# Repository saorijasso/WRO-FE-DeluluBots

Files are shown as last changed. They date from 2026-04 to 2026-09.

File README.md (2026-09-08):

WRO 2026 Future Engineers - DeluluBots
====

## Table Of Contents
1. [Team](#1-team)
2. [Our Robot](#2-our-robot)
3. [Hardware](#3-hardware)
    * 3.1. [Mobility Management](#31-mobility-management)
    * 3.2. [Power and Sense Management](#32-power-and-sense-management)
4. [Software](#4-software)
    * 4.1. [Computer Vision](#41-computer-vision)
    * 4.2. [Vehicle Control](#42-vehicle-control)
5. [DIY Game Field](#5-diy-game-field)  
6. [License](#6-license)

## 1. Team

<p align="center">
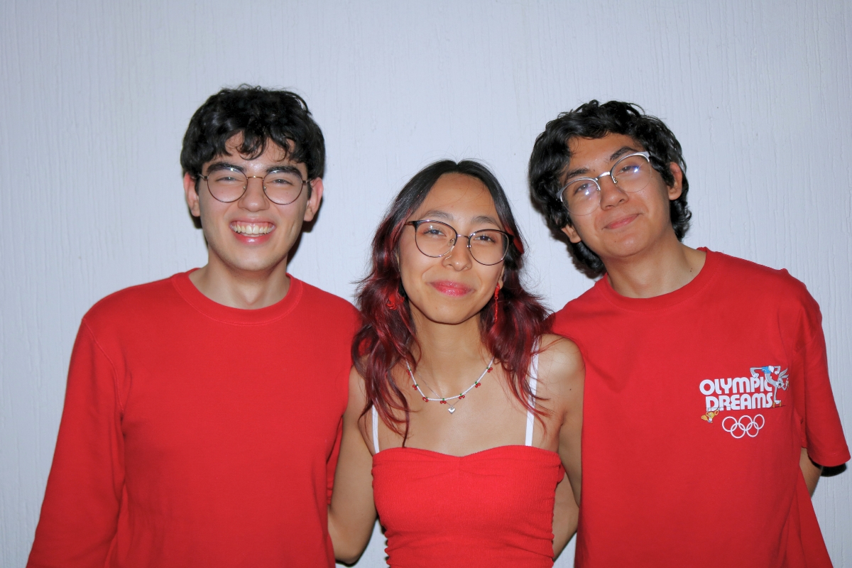
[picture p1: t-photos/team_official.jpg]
DeluluBots Official Team Photo
  
</p>

<p align="center">
  <strong>DELULUBOTS</strong><br>
  <em>Delulu Today, Limitless Tomorrow.</em>
</p>

We are **DeluluBots**, an independent robotics team of students passionate about **robotics, programming, electronics, and innovation**.

**DeluluBots was born from a simple but ambitious dream: to build our own robot and compete in WRO.** At the beginning, it seemed like a delulu idea—we had limited resources, little experience with many of the technologies involved, and no clear way to afford the journey ahead. But instead of seeing those limitations as a reason to stop, we saw them as a reason to start. That mindset became the foundation of our team.

> *Delulu* is an informal term for being “delusional” in an optimistic way: believing in something that may seem unrealistic and choosing to pursue it anyway.

Our journey is guided by one simple idea: **“Delulu Today, Limitless Tomorrow.”** As an independent team, we have worked hard to build a competitive robot while finding ways to make our participation possible. To help cover the costs of our robot and our trip to the national competition, we started **selling homemade cookies and spicy gummy candies in our city**. Every sale brought us one step closer to our goal.

More than building a robot, we aim to grow as people and engineers capable of **creating, innovating, and turning ideas into reality**. WRO has encouraged us to learn beyond what we are normally taught at university, explore technologies we had never worked with, and solve challenges independently.

Through every failure and iteration, we have learned that **perseverance is just as important as technical knowledge**. We are proud of how far we have come and excited to keep learning, improving, and staying *delulu*.

---

### Best & Fun Moments

<p align="center">
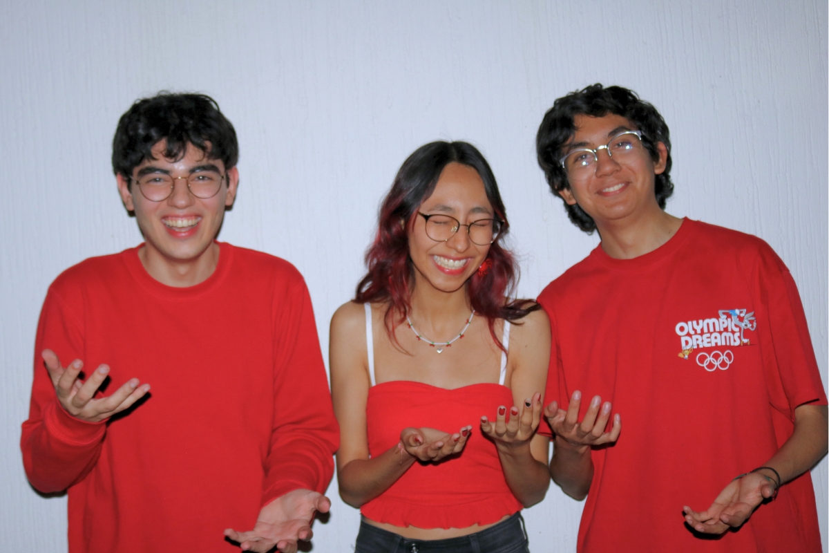
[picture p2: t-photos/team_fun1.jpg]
DeluluBots Fun Moment 1
  
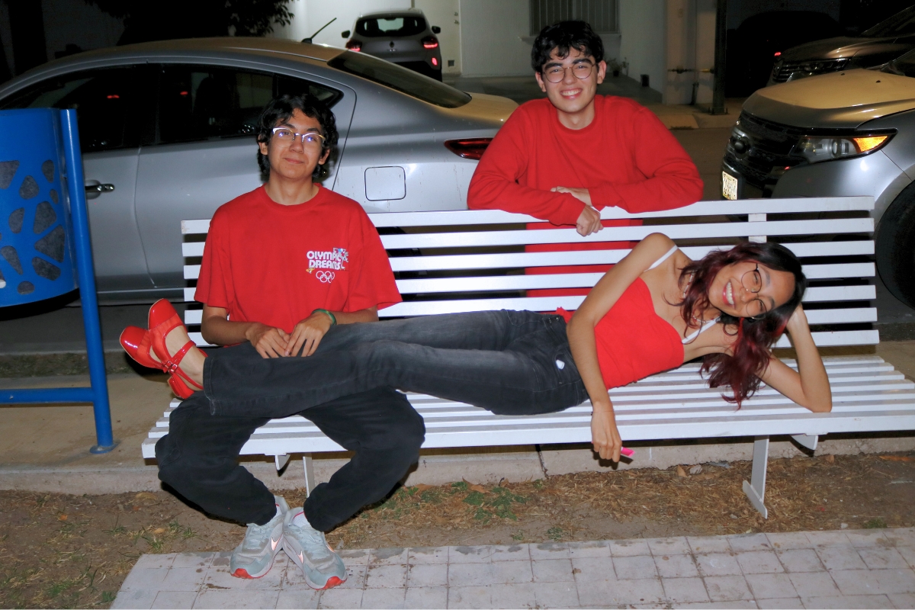
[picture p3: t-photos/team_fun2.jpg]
DeluluBots Fun Moment 2
  
</p>

<p align="center">
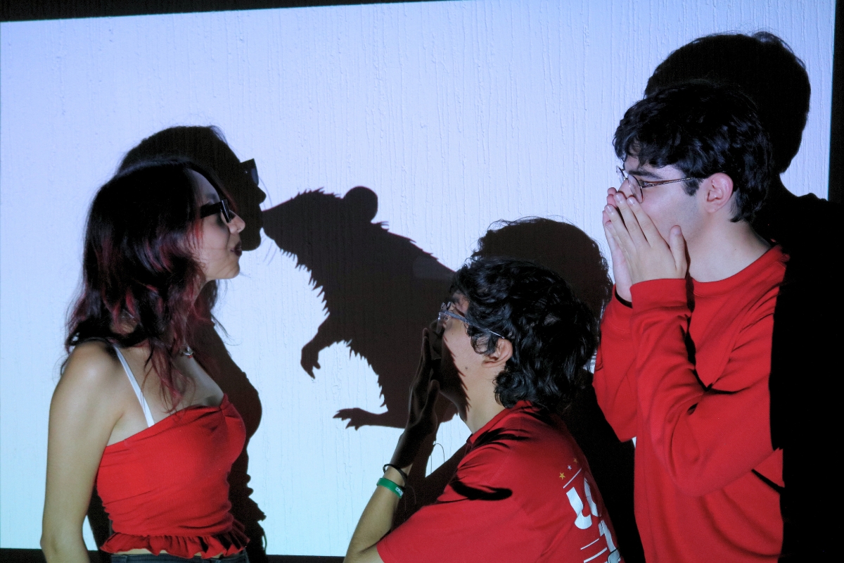
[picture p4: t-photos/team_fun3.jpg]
DeluluBots Fun Moment 3
  
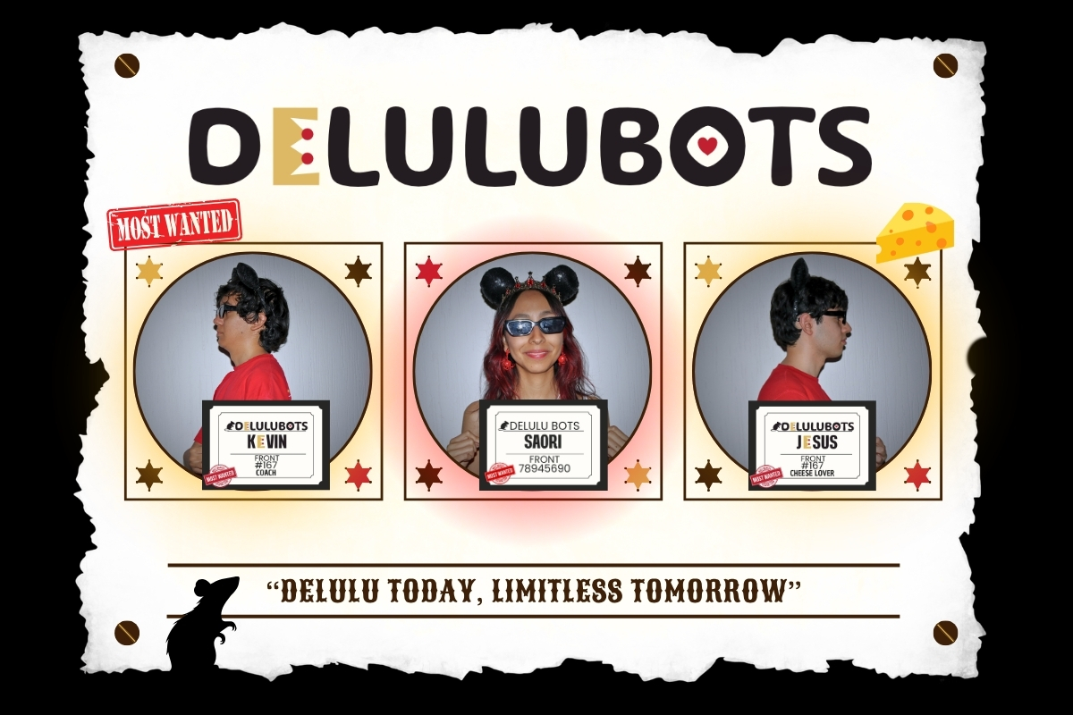
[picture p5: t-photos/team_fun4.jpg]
DeluluBots Fun Moment 4
  
</p>

---

### Team Members

<table>
<tr>
<td width="65%" valign="top">

## **Saori Jasso**

**Electronics · PCB Designer · Software Developer**

**Age:** 19

I am an **Information Technology Engineering student** and was responsible for the robot’s electrical system, from **selecting components and designing the PCB** to developing the systems that allow it to power on with just two buttons.

I also contributed to the **software development** and was responsible for **designing and building our DIY Game Field** for testing and practice.

WRO gave me the opportunity to design my **first PCB** and challenge myself with technologies I had never worked with before. Since middle school, robotics has been one of my greatest passions, and I hope to **inspire more girls to explore STEM, pursue engineering, and discover the same passion for robotics.**

</td>

<td width="35%" align="center" valign="middle">

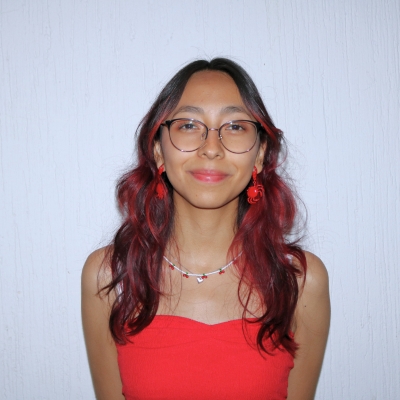
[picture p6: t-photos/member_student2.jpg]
Saori Jasso


</td>
</tr>
</table>

---

<table>
<tr>
<td width="65%" valign="top">

## **Jesús Morales**

**Mechanical & CAD Designer · Software Developer**

**Age:** 19

I am an **Information Technology Engineering student** and served as the Mechanical & CAD Designer and Software Developer for our robot.

This project marked my first time fully designing an **entire mechanical system from scratch in CAD**—a challenge that required balancing spatial constraints, weight distribution, and structural integrity.

My passion for technology started at a young age, but growing up in my hometown, hands-on STEM opportunities were limited. Moving to Mexico gave me the chance to explore robotics throughout my school years, shaping my path into engineering.

WRO has been an incredible opportunity to **push my technical limits**, and I hope to inspire others to pursue STEM regardless of their background.

</td>

<td width="35%" align="center" valign="middle">

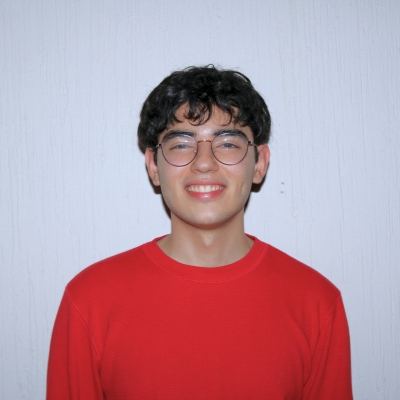
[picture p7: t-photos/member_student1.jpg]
Jesús Morales


</td>
</tr>
</table>

---

<table>
<tr>
<td width="65%" valign="top">

## **Kevin Rucoba**

**Coach**

**Age:** 21

I am a **Software Development Engineering student** and have supported and advised the team throughout all areas of the project.

From helping with **technical challenges and brainstorming ideas** to guiding decisions and overcoming unexpected problems, I've always been there to provide a different perspective when needed.

My goal is to **support their ideas, share my experience, and help them turn their ideas into reality** while encouraging them to learn, experiment, and grow as a team.

I also helped the team stay focused on our goals, encouraged us to keep improving after setbacks, and shared the experience needed to approach challenges with **confidence, creativity, and perseverance**.

</td>

<td width="35%" align="center" valign="middle">

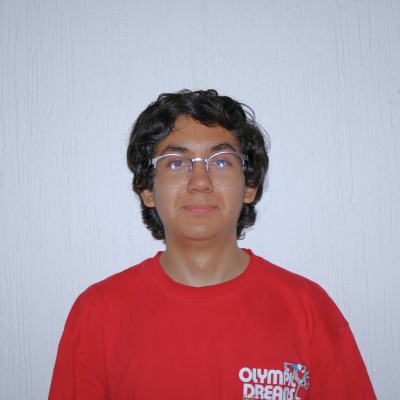
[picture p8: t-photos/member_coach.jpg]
Kevin Rucoba


</td>
</tr>
</table>

---

## 2. Our Robot

### Performance Videos

Take a look at our robot in action during the WRO 2026 Future Engineers challenges.

<table>
<tr>
<td align="center" width="50%">

<strong>Open Challenge</strong>

<a href="https://www.youtube.com/watch?v=468RyVULAOA">
  
</a>

<br>

<a href="https://www.youtube.com/watch?v=468RyVULAOA">
  Watch the Open Challenge Video
</a>

</td>

<td align="center" width="50%">

<strong>Obstacle Challenge</strong>

<a href="https://youtu.be/EnNW7pR3liw">
  
</a>

<br>

<a href="https://youtu.be/EnNW7pR3liw">
  Watch the Obstacle Challenge Video
</a>

</td>
</tr>
</table>

## 3. Hardware

### 3.1. Mobility Management

#### Chassis Overview

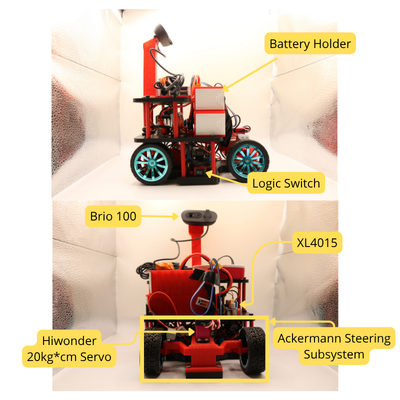
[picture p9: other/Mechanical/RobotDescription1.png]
Robot mechanical overview 1

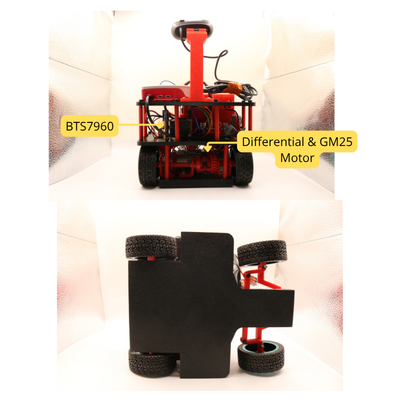
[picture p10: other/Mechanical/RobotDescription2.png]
Robot mechanical overview 2

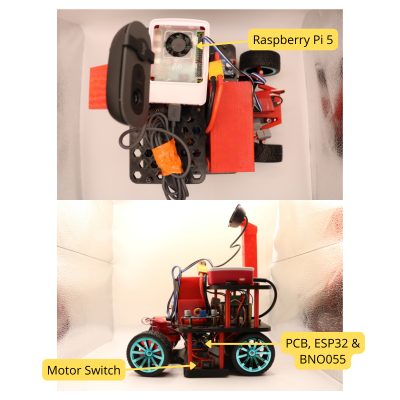
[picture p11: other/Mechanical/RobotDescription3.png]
Robot mechanical overview 3


*Overview of the robot showing the main mechanical subsystems, components and their relative positions.*

The mechanical design was developed as an integrated system, where the chassis provides the structural base for the drivetrain, steering mechanism, battery, camera, and other components. The position of each subsystem was selected according to the available space and the interaction between mechanical components.

#### Torque and Velocity Reasoning

When sizing our drivetrain, we started with basic longitudinal vehicle dynamics (Newton's 2nd law). Since the track is flat and we're moving relatively slowly, aerodynamic drag doesn't really matter. We only need to overcome inertia and rolling resistance to keep the robot moving.

**Base Parameters for our Model**

| Parameter | Value | Justification |
| :--- | :--- | :--- |
| **Robot mass (m)** | 1.45 kg | Operating just under the WRO 1.5 kg limit, maximizing our weight budget for structural reinforcement. |
| **Wheel radius (r)** | 32.5 mm | Measured from our 65 mm rubber tires. |
| **Target acceleration (a)** | 1.0 m/s² | Experimentally derived. Past 1.0 m/s², the wheels start slipping before the motor maxes out, and camera vibrations cause our vision pipeline to drop frames. |
| **Rolling resistance (Crr)** | ≈ 0.03 | Standard empirical estimate for rubber tires on synthetic surfaces. |
| **Gravity (g)** | 9.81 m/s² | Standard constant. |

> **Track Friction Unknown:** Since we couldn't afford the official competition mat, we built a DIY track using a standard tarpaulin (see our full guide in the [DIY Low-Cost Competition Track](#5-diy-game-field) section). We obviously can't measure exactly how its friction compares to the official 500 g/m² PVC mat. To compensate for this, we built a fairly large safety margin into our torque calculations.

**Force and Torque Math**

| Step | Formula | Result |
| :--- | :--- | :--- |
| **Inertial force** | Fa = m·a | 1.45 N |
| **Rolling resistance** | Frr = Crr·m·g | 0.427 N |
| **Wheel torque** | Tw = (Fa + Frr)·r | 0.061 N·m |
| **Required Motor torque** | Tm = Tw / η | **0.087 N·m** |

*Note: The 70% mechanical efficiency (η = 0.70) accounts for the friction we lose through our 3D-printed PETG differential (bevel gears and hex couplings).*

---

#### Motor and Driver Selection

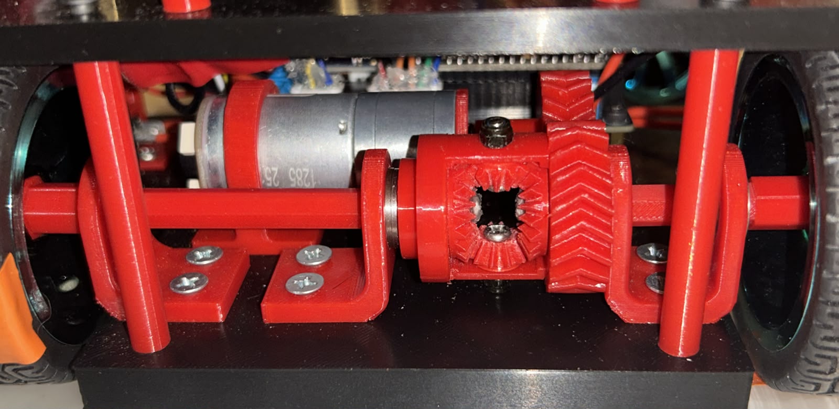
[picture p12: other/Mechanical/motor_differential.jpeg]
Image: GM25-370 motor mounted with PETG differential


**Motor: GM25-370, 12V, 330 RPM**  
The datasheet gives a continuous rated torque of 0.57 N·m (at 1.7 A) and a stall torque of 1.18 N·m (at 5.6 A). Since the robot is constantly driving and the wheels are never locked, we only use the continuous rating to size the system.

Our model requires 0.087 N·m, which is only about 15% of this motor's continuous capacity. We deliberately took the weight penalty of an oversized motor for a few practical reasons:
1. **Thermal Headroom:** Operating a motor near its limit generates a ton of heat. Staying at ~15% load keeps the motor completely cool, meaning we don't experience any RPM sag or battery voltage drops toward the end of a run.
2. **Friction Buffer:** If the official competition mat turns out to be much stickier than our tarp, this torque buffer gives us enough margin to avoid stalling in normal operation.
3. **Overcoming Mechanics:** The extra torque easily powers through the friction of our PETG differential, keeping our PID speed control crisp and responsive.

**Driver: Transitioning to the BTS7960**  
We originally prototyped with a TB6612FNG driver, but realized it was a major single point of failure. It's only rated for 1.2 A continuous per channel, and our motor can spike up to 5.6 A if it stalls (like bumping a wall or getting stuck).

Instead of risking a blown driver on the track, we swapped to a **BTS7960**. It’s rated for 43 A. It takes up more space on the chassis, but it greatly reduces the chance of the driver overheating. We chose reliability over spatial economy.

---

#### 3D Printing & Structural Optimization

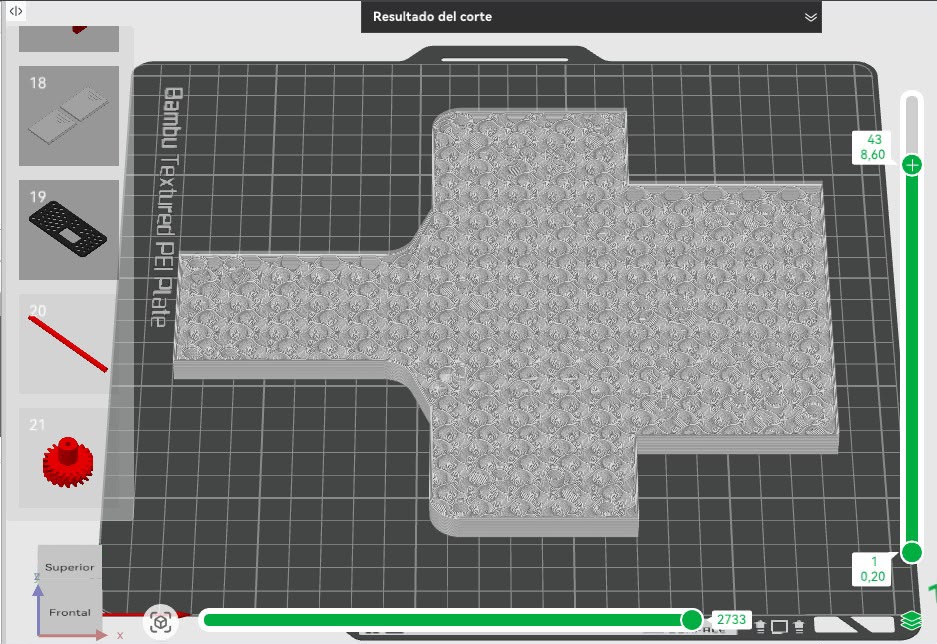
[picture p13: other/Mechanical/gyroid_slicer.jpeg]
Image: Gyroid infill pattern in slicer or printed part


To iterate quickly, we 3D printed all our custom mechanical parts using **PETG**, which gives us much better impact resistance and layer adhesion than standard PLA.

**Prototyping phase:**  
We printed early test fits using an **8% Gyroid infill**. It allowed us to print super fast and save filament during the trial-and-error phase. The Gyroid pattern distributes stress equally across the X, Y, and Z axes, so the pieces held their shape well. However, when we actively applied manual stress tests to find their limits, they eventually snapped. This proved they were strictly prototypes and nowhere near strong enough to survive the mechanical stress of a real competition.

**Final Production Parts:**  
For the final parts, we prioritized reliability so we optimized the slicer settings to get as much strength as possible without adding too much weight:
* **Wall Loops:** Increased from 2 to 3.
* **Top/Bottom Shells:** Increased from 2 to 3.
* **Gyroid Infill:** Bumped slightly to 15%.

**The result:** With these settings, we were able to add strength mainly where it matters without adding too much material. This kept our parts structurally rigid without unnecessarily increasing our total mass or messing up our calculated acceleration dynamics.

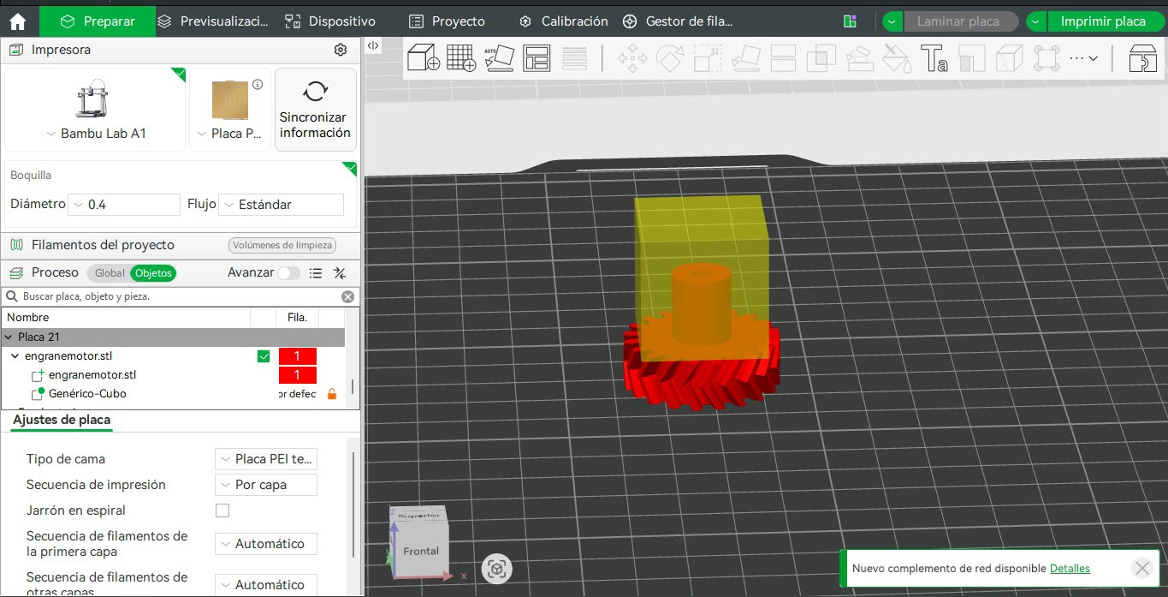
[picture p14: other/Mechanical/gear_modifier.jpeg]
Image: Slicer view showing cylindrical modifier on the D-shaft gear


**Targeted Reinforcement: Motor Gear Hub**  
During testing, we discovered a localized failure mode in our differential. The primary drive gear mounts directly to the motor's D-shaft. Due to the continuous torque and friction from sudden acceleration, the D-shaped hole inside the PETG gear was deforming and wearing out into a circle, causing the motor shaft to spin freely without turning the transmission.

Instead of printing the entire gear with 100% infill (which would add unnecessary mass and print time), we added a cylindrical modifier in Bambu Studio specifically around the mounting hub. We assigned 6 wall loops exclusively to this modifier. This generated a highly dense, rigid core to grip the D-shaft perfectly, while leaving the outer gear teeth at the standard 15% infill, solving the stripping issue completely.

#### Steering and Traction Mechanism

We selected an **Ackermann steering system** based on the turning requirements of our robot and the characteristics of the competition field. We considered conventional steering, Ackermann steering, and anti-Ackermann steering as possible solutions.

| Steering System | Turning Geometry | Tire Slip | Low-Speed Maneuverability | Mechanical Complexity | Alignment Requirements | Suitability for Our Robot |
| :--- | :--- | :--- | :--- | :--- | :--- | :--- |
| **Conventional Steering** | Both front wheels use approximately the same steering angle | Higher during tight turns because the wheels follow different turning radii | Moderate | Low | Low | Limited |
| **Ackermann Steering** | Inner wheel turns more than the outer wheel, allowing both wheels to follow their respective turning radii | Low | High | Medium | Medium–High | **Excellent** |
| **Anti-Ackermann Steering** | Inner wheel turns less than the outer wheel | Can be advantageous in specific high-speed conditions, but may increase slip at low speeds | Low–Moderate for our application | Medium | Medium–High | Limited |

We selected Ackermann because it allows the inner and outer front wheels to follow different turning radii, reducing unnecessary tire slip during turns and providing more predictable steering behavior.

This decision was also connected to our drivetrain architecture. Since the robot uses mechanically driven wheels rather than independently controlled drive wheels, we needed a steering solution that could provide precise directional control without using differential wheel speeds as the steering mechanism. Ackermann steering allowed us to separate the steering function from the traction system while maintaining a compact mechanical architecture.

#### Steering Geometry

The steering geometry was designed in CAD using the Ackermann principle. Instead of assigning the same steering angle to both front wheels, we constructed the geometry so that the steering axes of the front wheels converge toward a common **instantaneous center of rotation**.

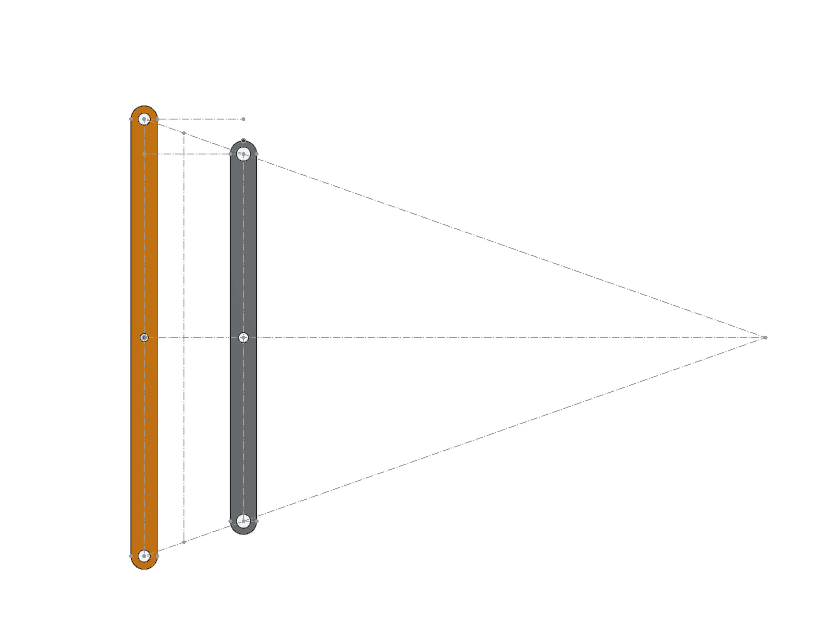
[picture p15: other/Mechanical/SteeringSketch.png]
Ackermann steering geometry


*CAD construction used to define the Ackermann steering geometry.*

This geometry determines the relative steering angles of the front wheels: the **inner wheel turns through a greater angle than the outer wheel** because it follows a smaller turning radius. This reduces unnecessary tire slip and allows the robot to maintain a more predictable trajectory during turns.

The CAD sketch was used to determine the position of the steering pivots and linkage attachment points before manufacturing the mechanism. This allowed us to translate the theoretical Ackermann geometry into a physical linkage while accounting for the available space, wheel position, and required steering range.

The steering mechanism consists of the **steering servo, servo arm, fixed steering support, linkage rods, steering arms, and front wheel assemblies**. The servo provides the input rotation, which is transferred through the linkage to both steering arms. The geometry of the steering arms produces the different steering angles required by the Ackermann configuration.

#### Space Optimization

The front section of the robot had limited space because the **front wheels, steering mechanism, and servo** had to fit within the same area. Rather than adding a separate structure to support the steering linkage, we integrated the **servo mount with the fixed steering support**.

The servo mount therefore serves two functions: it securely holds the servo and acts as the stationary reference point for the steering linkage. Small arms extending from this support provide the attachment points for the linkage rods, while the rest of the steering mechanism moves around this fixed structure.

This integration reduced the number of separate components and allowed us to make better use of the available space. It also reduced material usage while maintaining the rigidity required by the steering mechanism.

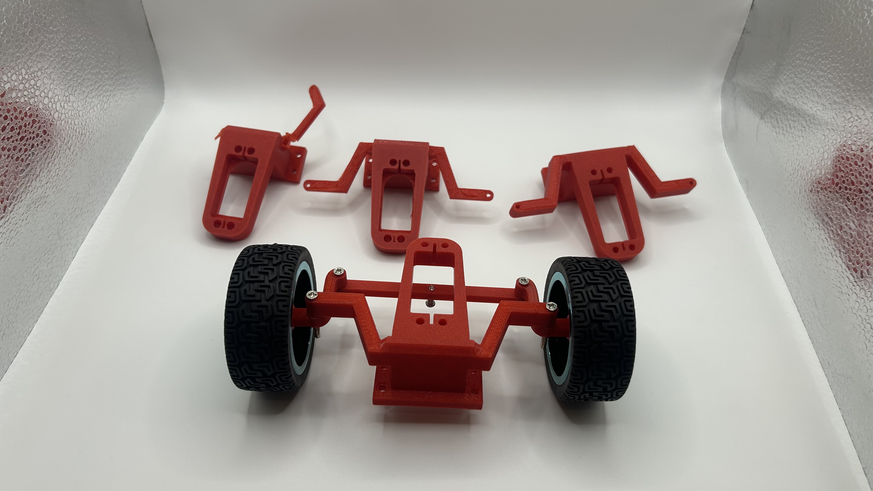
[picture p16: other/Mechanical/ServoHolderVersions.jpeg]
Servo support iterations


*Evolution of the servo support through different design iterations, showing the modifications made to improve its integration, stability, and fit within the steering mechanism.*

This was an example of adapting the theoretical steering geometry to the physical constraints of the robot rather than treating the steering system independently from the rest of the chassis.

#### Mechanical Differential

The Ackermann steering geometry also created a requirement for the traction system: the driven wheels need to be able to rotate at **different speeds during a turn**.

During a turn, the inner wheel follows a smaller radius than the outer wheel and therefore travels a shorter distance. If both driven wheels were rigidly connected to the same axle, they would be forced to rotate at the same speed. This would cause tire slip and introduce additional mechanical stress.

To solve this, we implemented a **mechanical open differential**. This allows both driven wheels to receive power from the same drivetrain while permitting them to rotate at different speeds when cornering.

We selected a mechanical differential because it provides this speed difference mechanically, without requiring independent control of the driven wheels. This complements the Ackermann steering geometry while keeping the drivetrain compact.

The differential uses **20-tooth side gears and 12-tooth spider gears**. The side gears are connected to the driven axles, while the spider gears transfer torque between them and allow relative rotation between the two sides.

The main drive gear maintains a **1:1 relationship with the motor output**, preserving the available motor speed without introducing an additional reduction stage at the differential.

#### Differential Iterations

Our drivetrain went through several iterations before reaching the final configuration. The first prototype used **spur gears** both in the motor-to-differential transmission and within the differential.

| Initial Prototype | Final Design |
| :---: | :---: |
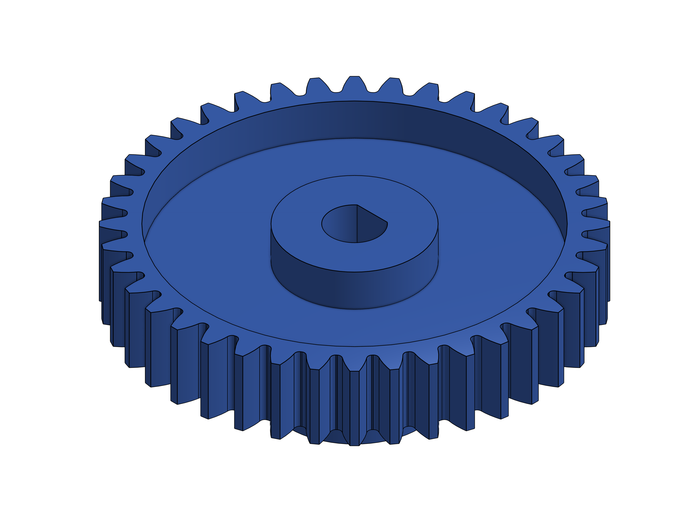
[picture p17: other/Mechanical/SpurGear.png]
Initial motor gear
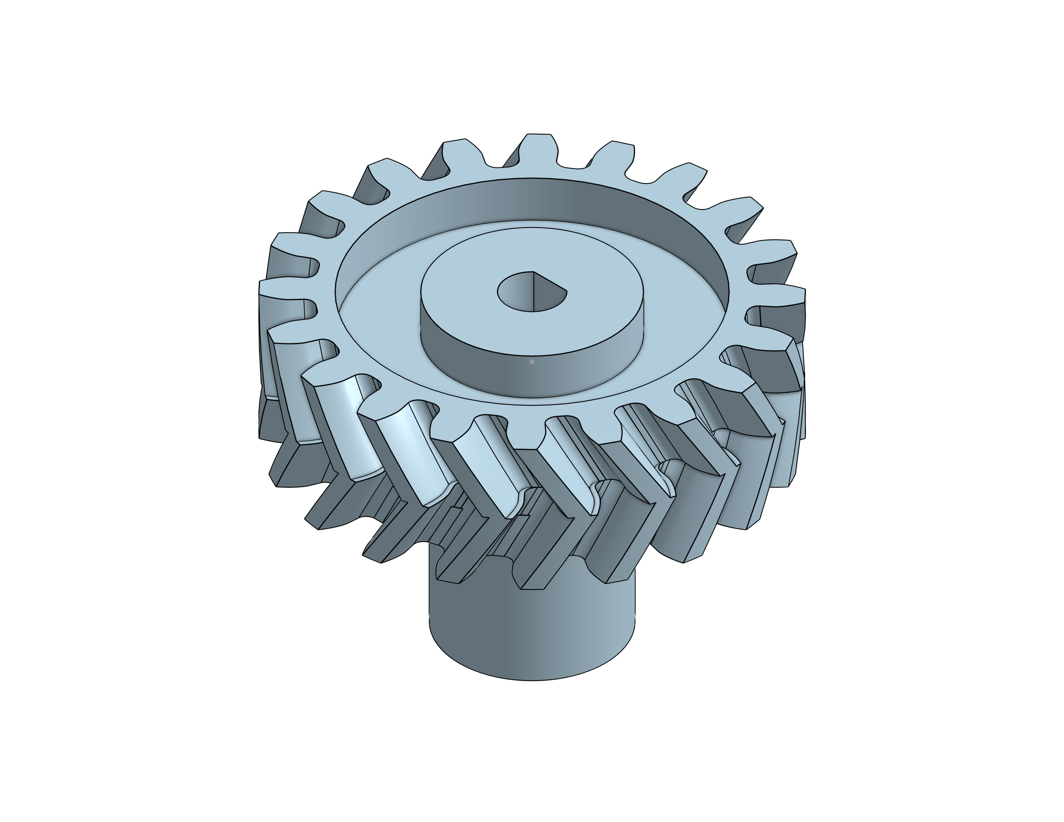
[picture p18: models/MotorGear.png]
Final motor gear
|  |  |
| *Spur gear* | *Final reinforced gear* |
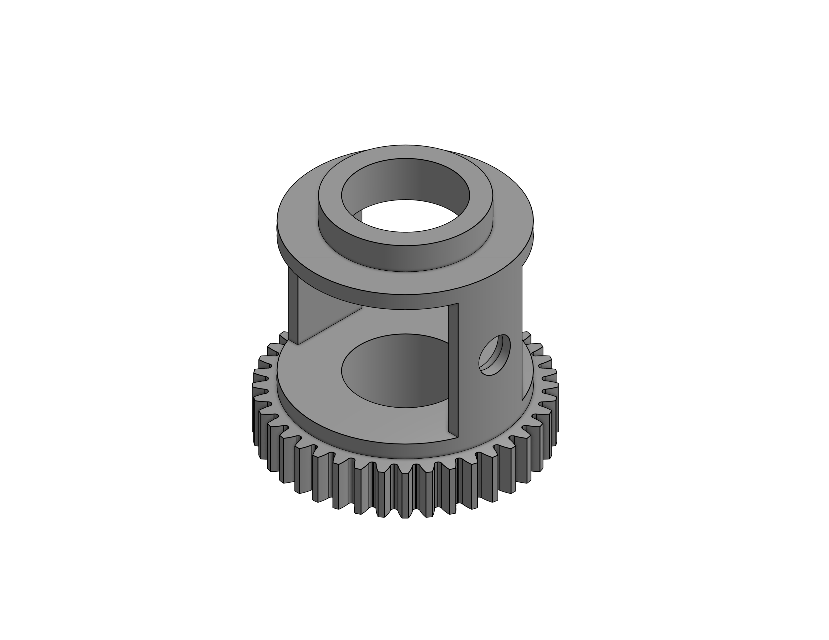
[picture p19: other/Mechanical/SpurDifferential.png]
Initial differential
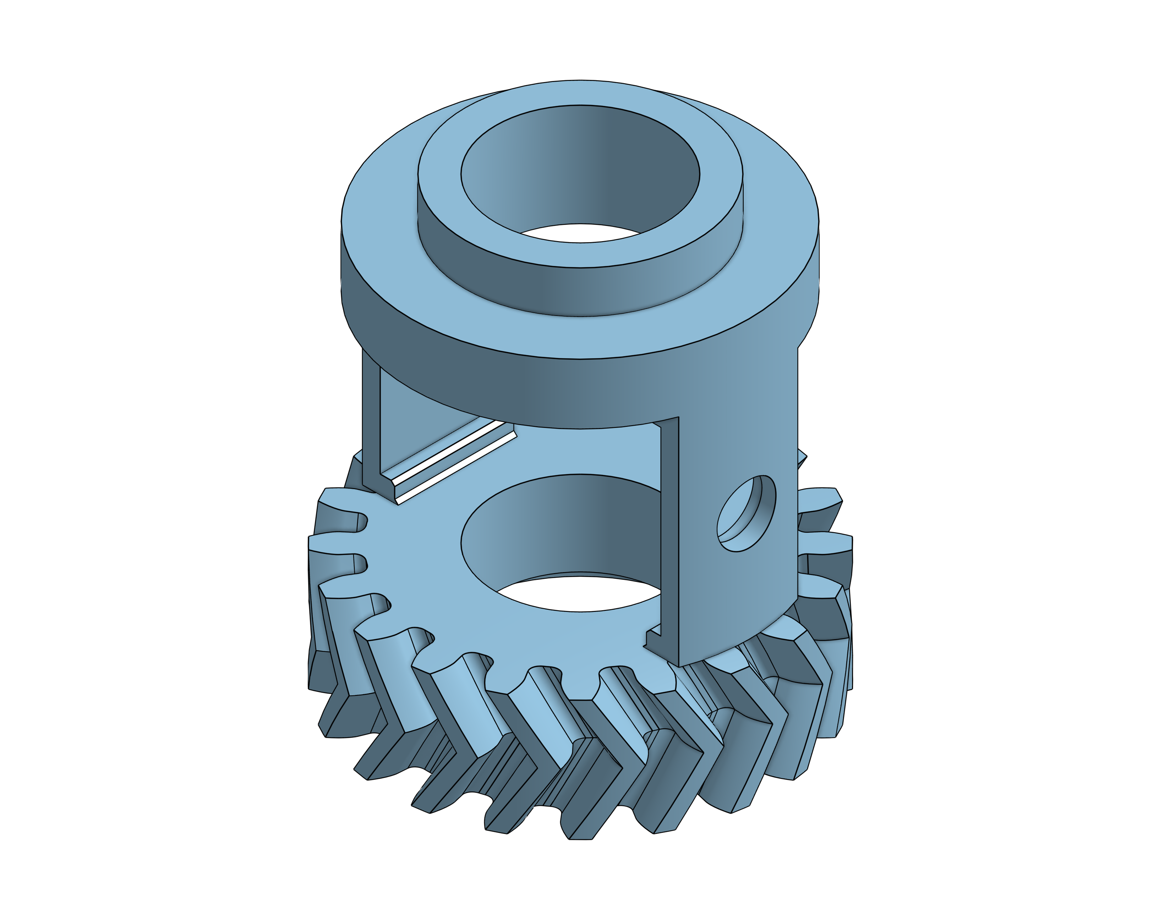
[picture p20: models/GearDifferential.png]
Final differential
|  |  |
| *Initial differential* | *Final differential* |

*Evolution of the drivetrain from the initial spur-gear prototype to the final design.*

The initial version allowed us to validate the basic drivetrain concept and confirm the interaction between the motor and differential. However, testing revealed several mechanical weaknesses that led to subsequent iterations.

The main gears were initially designed as **spur gears**. We later changed them to **herringbone gears** to improve resistance to lateral movement and maintain better alignment during operation.

#### Axle Support Iteration

During testing of the initial differential housing, we observed that the driven axles were supported at only two points. This allowed the shafts to deflect under their own load and during operation, causing them to become slightly misaligned with the differential gears.

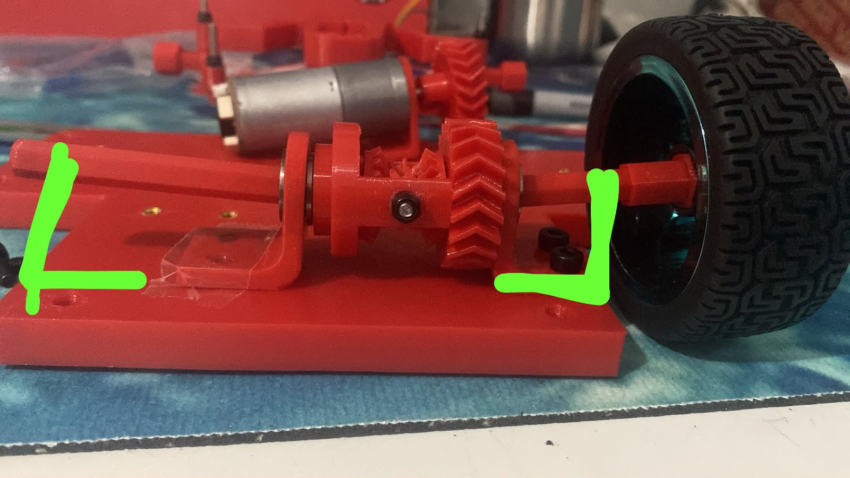
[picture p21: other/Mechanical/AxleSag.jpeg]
Initial axle support


*Initial axle configuration showing shaft deflection caused by insufficient support.*

To address this issue, we redesigned the rear support structure to provide an additional support point for the driven axles.

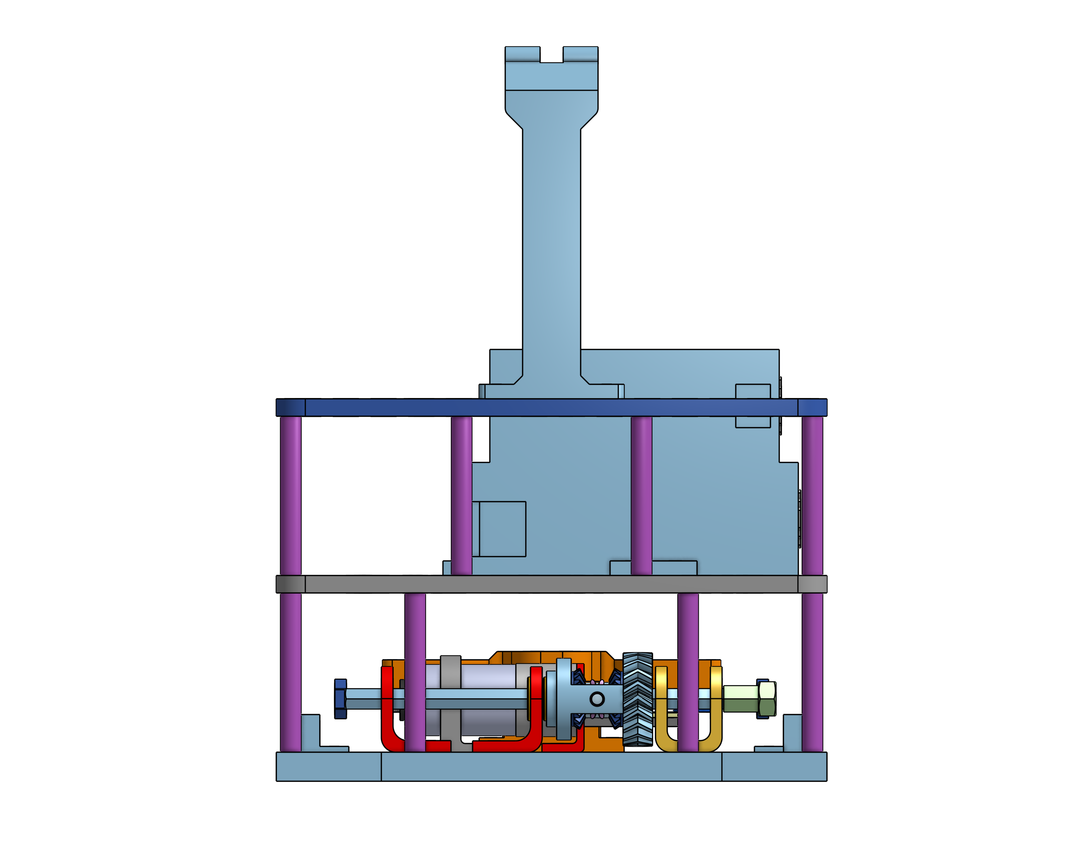
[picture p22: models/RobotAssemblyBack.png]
Axle support redesign


*Axle support redesign adding an additional constraint point to reduce shaft deflection.*

The additional support constrains the shafts along a greater portion of their length, reducing unwanted movement and helping maintain consistent alignment between the axles and the differential gears.

This modification was made specifically in response to the deformation observed during testing. Rather than increasing the overall size of the differential housing, we added support only where the deformation occurred. This improved structural stability while keeping the mechanism compact.

Additionally, the supports holding the spider gears were initially too thin and fragile. We increased their thickness and added reinforcing tabs connecting them to the main differential body. Because changing the spacing between these supports would affect the existing gear geometry, the reinforcement was added without changing their position.

Finally, during testing of the first herringbone version, the main gears could still separate slightly under load, causing the teeth to skip. We modified the differential housing to keep the gears closer together and maintain consistent tooth engagement.

These iterations allowed us to improve the drivetrain based on problems observed during physical testing, resulting in a final differential with improved **gear alignment, shaft support, structural rigidity, and power transmission reliability**.

#### Motor Support

The motor support was developed to securely hold the drive motor while maintaining its position relative to the drivetrain. In the initial version, the motor was not fully enclosed by the support structure.

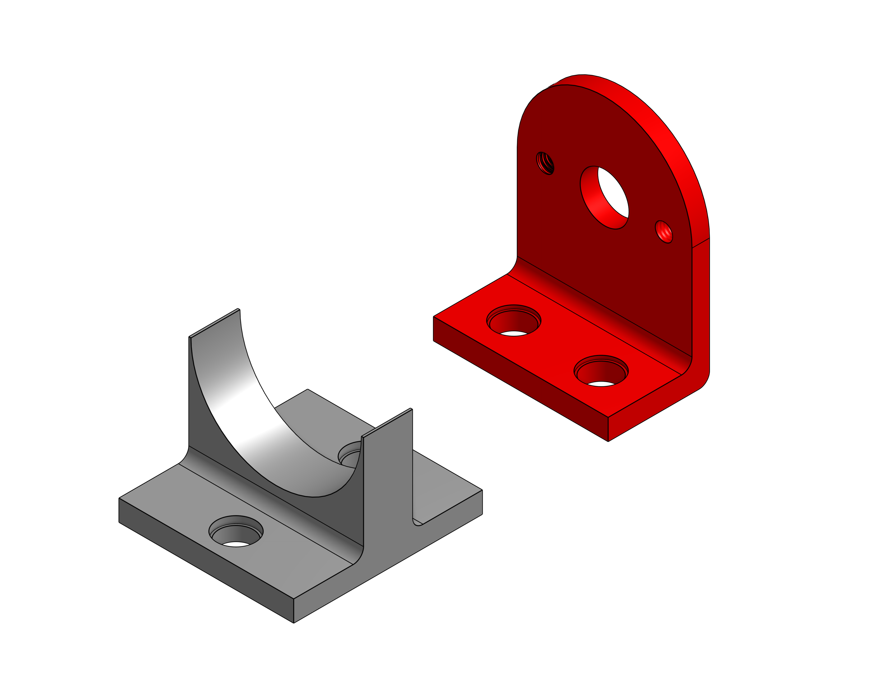
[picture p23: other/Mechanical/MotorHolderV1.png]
Initial motor support


*Initial motor support design with limited constraint around the motor.*

During testing, we observed that the torque generated by the motor caused the support to tend to move upward. This movement could affect the position of the motor and consequently the alignment between the motor output gear and the drivetrain.

To address this issue, we redesigned the support to provide greater constraint around the motor body.

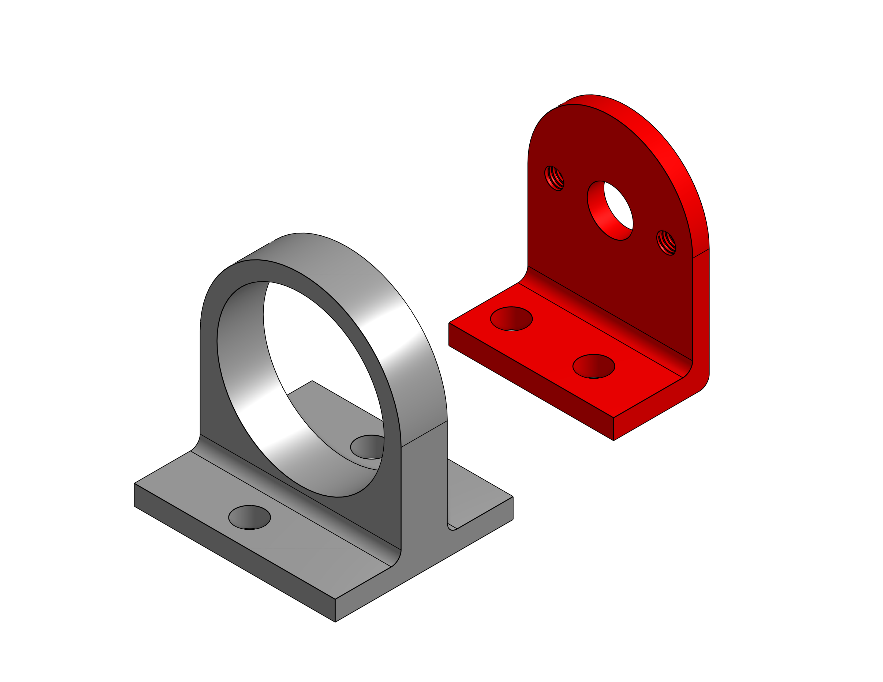
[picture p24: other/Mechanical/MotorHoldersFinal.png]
Final motor support


*Final motor support design providing greater constraint around the motor.*

The modification increased the stability of the motor mounting structure and helped maintain consistent alignment with the drivetrain during operation. Rather than increasing the size of the surrounding chassis, the support was reinforced specifically in the areas where movement was observed.

### 3.2. Power and Sense Management
This section details the hardware architecture of our vehicle, covering **component selection and strategic placement**, **power distribution**, **wiring schematics (including custom PCB design)**, **sensor calibration protocols**, and **systematic power testing strategies**.

Our design methodology goes beyond connecting components to achieve basic functionality. We engineered an electrical ecosystem focused on **reproducibility**, **safety**, **noise isolation**, and **rapid pre-competition validation**—ensuring every hardware decision directly supports our vehicle’s autonomous performance goals.

> [!NOTE]
> **Key Engineering Focus:** Prioritizing power stability through dual-battery domain isolation, noise decoupling, and custom PCB power distribution to withstand dynamic competition conditions.

### Section Overview

This module is organized into six core architecture deliverables:

<table>
  <thead>
    <tr>
      <th width="30%">Module</th>
      <th width="70%">Key Deliverables & Specifications</th>
    </tr>
  </thead>
  <tbody>
    <tr>
      <td><b>01. Control Architecture</b></td>
      <td>Dual-controller processing hierarchy (Raspberry Pi 5 + ESP32) and UART communication flow.</td>
    </tr>
    <tr>
      <td><b>02. Power System Architecture</b></td>
      <td>Dual-domain battery isolation (2500 mAh logic & 2300 mAh actuators), voltage regulation rails, and safety protocols.</td>
    </tr>
    <tr>
      <td><b>03. Power Budget & Runtime</b></td>
      <td>Worst-case current consumption matrix, mathematical power models, and battery life estimations.</td>
    </tr>
    <tr>
      <td><b>04. Component Specifications</b></td>
      <td>Comprehensive procurement matrix, hardware parameters, engineering rationale, and placement strategy.</td>
    </tr>
    <tr>
      <td><b>05. Iterative Hardware Prototyping</b></td>
      <td>Pre-PCB circuit mapping, hand-drawn schematics, and preliminary electrical testing.</td>
    </tr>
    <tr>
      <td><b>06. Custom PCB Integration</b></td>
      <td>Carrier board design, dual-switch power activation, decoupling strategies, and trace routing.</td>
    </tr>
  </tbody>
</table>

---

### Control Architecture

The vehicle's electronics rely on a distributed processing hierarchy, separating high-level perception and computer vision from real-time low-level actuation:

```text
┌────────────────────────────────┐                 ┌────────────────────────────────┐
│        Raspberry Pi 5          │   UART Serial   │              ESP32             │
│  (High-Level Vision & Logic)   │ ──────────────> │  (Low-Level Real-Time Control) │
└───────────────┬────────────────┘                 └───────────────┬────────────────┘
                │                                                  │
         USB    │                                   PWM / I2C / IO │
                ▼                                                  ▼
   ┌──────────────────────────┐                      ┌──────────────────────────┐
   │    Logitech Brio 100     │                      │ Actuators & Sensors      │
   │    (1080p Camera)        │                      │ (Motor, Servo, IMU)      │
   └──────────────────────────┘                      └──────────────────────────┘
```

* **Raspberry Pi 5 (Vision & Logic):** Processes the camera feed using OpenCV to detect the track boundaries. It acts as the main decision-maker, calculating the necessary steering angle, motor power, and evaluating state conditions (e.g., boolean flags for lap counting or current run state). It sends these specific variables to the ESP32 via UART serial communication.
* **ESP32 (Hardware Control):** Receives the angle, power, and state commands from the Raspberry Pi. It acts as the physical bridge: reading data from the BNO055 IMU and motor encoder, and translating the Pi's commands into actual PWM signals to drive the BTS7960 motor driver and steering servo.

---

### Electrical System Architecture

<p align="center">
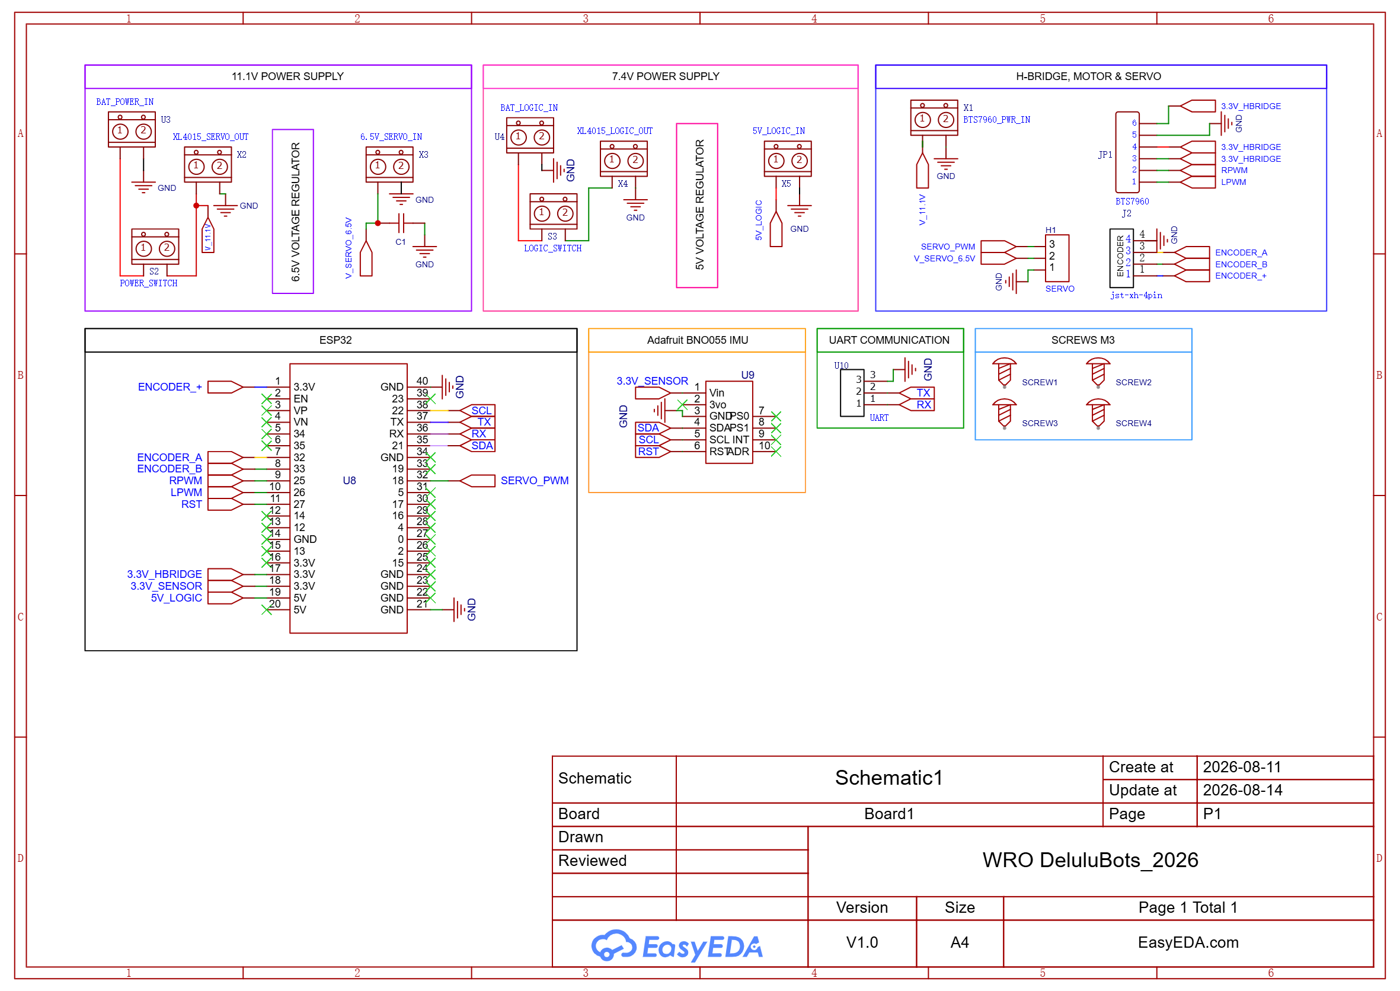
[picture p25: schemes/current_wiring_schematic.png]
Current Wiring Schematic
  
  <br>
  <em>Official electrical schematic detailing power distribution and signal routing.</em>
</p>

#### Dual-Battery Domain Isolation

To eliminate voltage dips (brownouts) and inductive noise caused by high-current motor actuation, the electrical system is divided into two fully isolated power domains:

* **Logic & Perception Domain (7.4V LiPo, 2500 mAh 2S):** Powers low-voltage digital hardware, sensors, processing boards, and the USB camera.
* **Actuator Domain (11.1V LiPo, 2300 mAh 3S):** Supplies raw current to mechanical loads, isolating inductive back-EMF and switching noise from sensitive processing logic.

```text
┌────────────────────────────────────────────────────────────────────────┐
│                        ACTUATOR POWER DOMAIN                           │
└────────────────────────────────────────────────────────────────────────┘
                       ┌──────────────────────┐
                       │   11.1 V LiPo        │
                       │   2300 mAh (3S)      │
                       └──────────┬───────────┘
                                  │
                   ┌──────────────┴──────────────┐
                   │                             │
              Direct 11.1 V                 ┌────▼────┐
                   │                        │ XL4015  │
                   ▼                        │  6.5 V  │
             ┌───────────┐                  └────┬────┘
             │  BTS7960  │                       │
             └─────┬─────┘                  ┌────┴─────┐
                   │                        │ Hiwonder │
                   ▼                        │ 20kg·cm  │
              ┌─────────┐                   │  Servo   │
              │ GM25    │                   └───────────┘
              │ Motor   │
              └─────────┘

┌────────────────────────────────────────────────────────────────────────┐
│                          LOGIC POWER DOMAIN                            │
└────────────────────────────────────────────────────────────────────────┘
                       ┌──────────────────────┐
                       │   7.4 V LiPo         │
                       │   2500 mAh (2S)      │
                       └──────────┬───────────┘
                                  │
                             ┌────▼────┐
                             │ XL4015  │
                             │  5.0 V  │
                             └────┬────┘
                                  │
                    ┌─────────────┴─────────────┐
                    │                           │
              ┌─────▼─────┐               ┌─────▼─────┐
              │   ESP32   │               │ Raspberry │
              └─────┬─────┘               │   Pi 5    │
                    │                     └─────┬─────┘
       ┌────────────┼────────────┐              │
       │            │            │          USB │
   ┌───▼────┐  ┌────▼───┐  ┌─────▼─────┐        ▼
   │Encoder │  │ BNO055 │  │   UART    │  ┌───────────────┐
   │        │  │  IMU   │  │ Interface │  │ Logitech Brio │
   └────────┘  └────────┘  └───────────┘  │  100 Webcam   │
                                          └───────────────┘
```

> [!IMPORTANT]
> **Noise Suppression:** A 220 nF ceramic capacitor is placed in parallel across the servo power rail (+V/GND) to suppress high-frequency inductive voltage spikes generated by sudden mechanical steering shifts.

#### Voltage Regulation & Pre-Power Safeguards

Two XL4015 DC-DC Buck Converters step down variable battery voltages into regulated power rails:

| **Input Source** | **Regulated Output** | **Target Payloads** | **Primary Purpose** |
| --- | --- | --- | --- |
| **7.4V LiPo (2S, 2500 mAh)** | **5.0V DC** | ESP32, Raspberry Pi 5, Sensors, Camera | Clean digital rail preventing MCU/SBC brownouts. |
| **11.1V LiPo (3S, 2300 mAh)** | **6.5V DC** | Hiwonder 20 kg·cm Steering Servo | Dedicated high-torque servo rail isolated from logic. |

> [!WARNING]
> **Safety Protocol:** Buck converter output voltages are manually verified using a digital multimeter prior to connecting any microcontrollers, ensuring no over-voltage reaches 5V sensitive logic lines.
>
> | **Testing Logic Rail (5.0V)** | **Testing Actuator Rail (6.5V)** |
> | :---: | :---: |
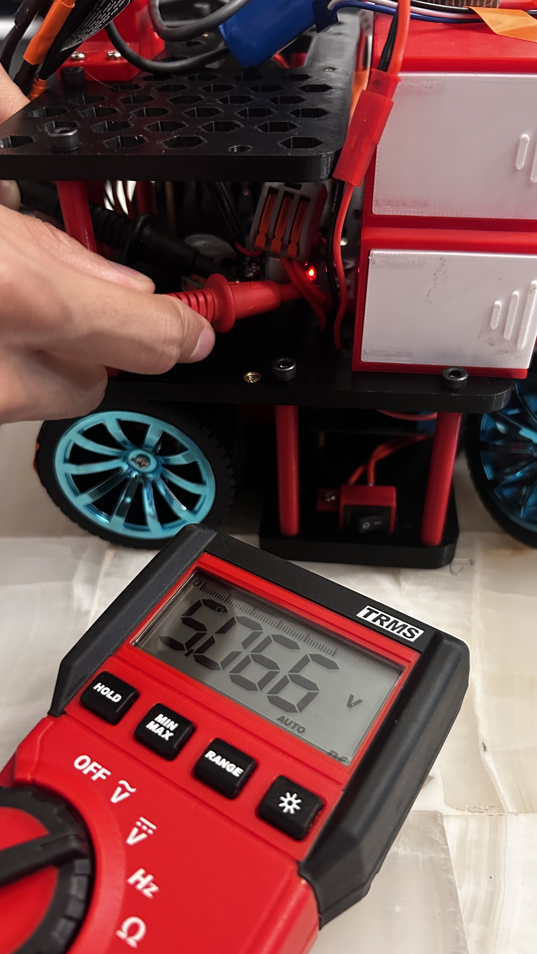
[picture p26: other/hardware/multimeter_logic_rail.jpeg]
Multimeter checking 5V buck converter
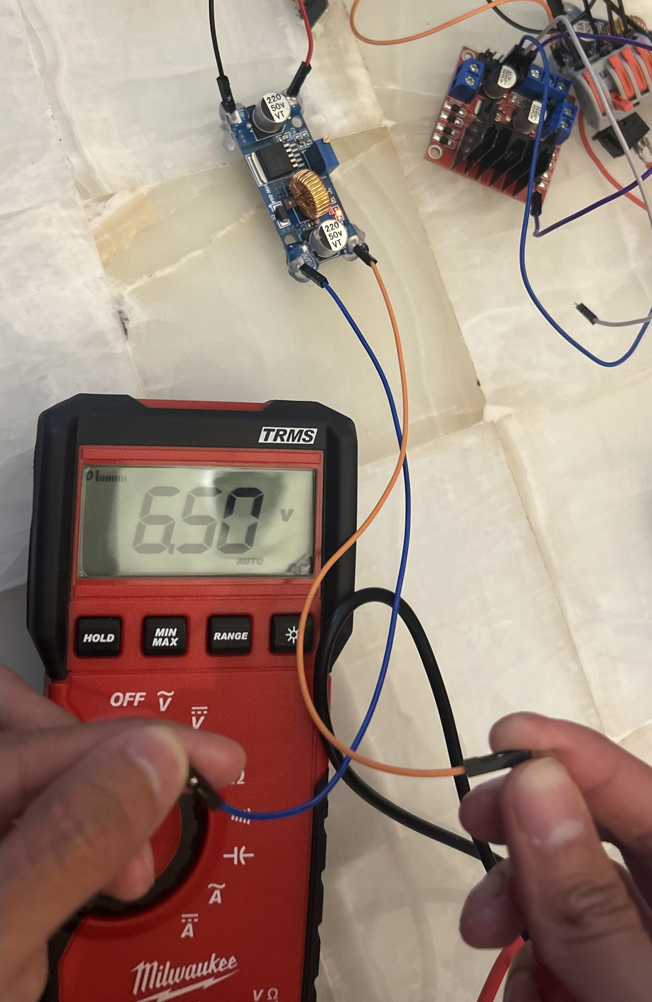
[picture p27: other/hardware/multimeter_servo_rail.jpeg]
Multimeter checking 6.5V buck converter
> |  |  |
---

### Reliability and Safety Considerations

#### Reverse Polarity Prevention

One of the most critical foreseeable assembly failures during rapid pit-stop battery swaps is reverse polarity connection. To eliminate this risk, the power distribution system does not rely solely on color-coded wire conventions (red/black):

* **Actuator Domain (11.1 V LiPo):** Terminates in a high-current **keyed XT60 connector**.
* **Logic Domain (7.4 V LiPo):** Terminates in a dedicated **keyed JST-RC connector**.

Because both connector families are mechanically polarized and asymmetrical, they physically prevent inverted insertion. This implements a reliable mistake-proofing (poka-yoke) physical safeguard, eliminating human error during high-stress competition maintenance.

---

### Current Requirements & Power Budget

#### Component Current Demand Matrix

| **Component** | **Operating Voltage** | **Current Demand / Profile** | **Supply Source** |
| --- | --- | --- | --- |
| **GM25-370 Motor** | 11.1 V | ≤ 1.7 A (Nominal) \| ≤ 5.6 A (Stall) | Direct 11.1V LiPo (3S, 2300 mAh) |
| **BTS7960 Driver** | 11.1 V | Rated up to 43 A max peak | Direct 11.1V LiPo (3S, 2300 mAh) |
| **Hiwonder Servo** | 6.5 V | Variable dynamic load (≈ 0.8 A – 2.0 A) | 11.1V LiPo → XL4015 Buck (#2) |
| **Raspberry Pi 5** | 5.0 V | High-performance digital load (≈ 1.5 A – 3.0 A) | 7.4V LiPo → XL4015 Buck (#1) |
| **ESP32 MCU** | 5.0 V | Nominal logic load (≈ 160 mA – 240 mA) | 7.4V LiPo → XL4015 Buck (#1) |
| **BNO055 IMU** | 3.3 V Logic | Low power sensor load (< 15 mA) | ESP32 Onboard 3.3V Regulator |
| **Logitech Brio 100** | 5.0 V (USB) | Powered directly via USB bus | Raspberry Pi 5 USB Port |

#### Mathematical Power Calculations

Electrical power consumption is defined by:

**P = V × I**

**1. Nominal Motor Power Consumption:**
P(motor_nom) = 11.1 V × 1.7 A = 18.87 W

**2. Worst-Case Stall Electrical Condition:**
P(motor_stall) = 11.1 V × 5.6 A = 62.16 W

*The stall power (62.16 W) represents an instantaneous transient condition used to dimension PCB trace widths and thermal clearance margins.*

#### Battery Runtime Estimation

Theoretical operational runtime (t) is estimated using nominal battery capacities:

**t ≈ Capacity (Ah) / Average Current (A)**

* **Actuator Rail (11.1V LiPo, 2300 mAh):**
  Actuator Runtime ≈ 2.3 Ah / 1.7 A ≈ 1.35 hours (≈ 81 minutes)

* **Logic Rail (7.4V LiPo, 2500 mAh):**
  Logic Runtime ≈ 2.5 Ah / 2.0 A ≈ 1.25 hours (≈ 75 minutes)

> **Real-World Operating Margin:** Accounting for ≈ 90% DC-DC buck efficiency, CPU vision spikes, and keeping battery discharge above 20% capacity (3.3V/cell cutoff), total continuous competition runtime is estimated at **45–55 minutes**, far exceeding the required competition run length.

---

### Component Selection & Specifications

The following table details the key electronic and electromechanical components selected for our vehicle, including their core technical parameters, functional role, power/interface requirements, and engineering rationale.

<table>
  <thead>
    <tr>
      <th width="11%">Component</th>
      <th width="8%">Image</th>
      <th width="20%">Key Specifications</th>
      <th width="16%">Function</th>
      <th width="20%">Power / Interface</th>
      <th width="25%">Selection Rationale</th>
    </tr>
  </thead>
  <tbody>
    <tr>
      <td><b>GM25-370 Geared Motor</b><br><i>(with encoder)</i></td>
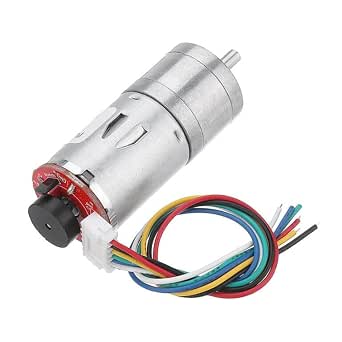
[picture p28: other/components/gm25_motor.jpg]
GM25 Motor
      <td align="center"></td>
      <td>
        • 12V Nominal<br>
        • 330 RPM<br>
        • Metal Gearbox<br>
        • Integrated Encoder
      </td>
      <td>Drive Propulsion</td>
      <td>11.1V Battery via BTS7960 Driver</td>
      <td>Provides high torque and high encoder resolution for precise closed-loop speed control.</td>
    </tr>
    <tr>
      <td><b>BTS7960 Motor Driver</b></td>
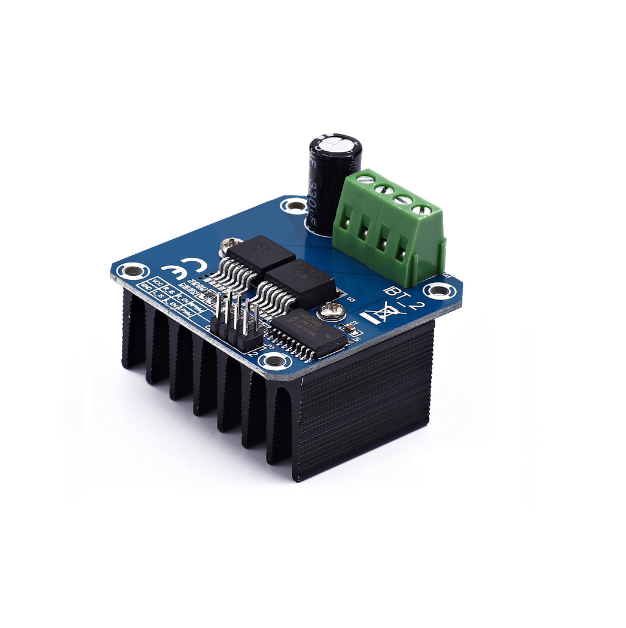
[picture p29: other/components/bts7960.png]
BTS7960 Driver
      <td align="center"></td>
      <td>
        • Max Current: 43A<br>
        • Operating Voltage: 6V–27V<br>
        • Thermal Protection
      </td>
      <td>High-Current Motor Control</td>
      <td>11.1V Power Rail + ESP32 Logic PWM/DIR</td>
      <td>Offers high current headroom, preventing thermal shutdown during heavy load or acceleration.</td>
    </tr>
    <tr>
      <td><b>Hiwonder Digital Servo</b></td>
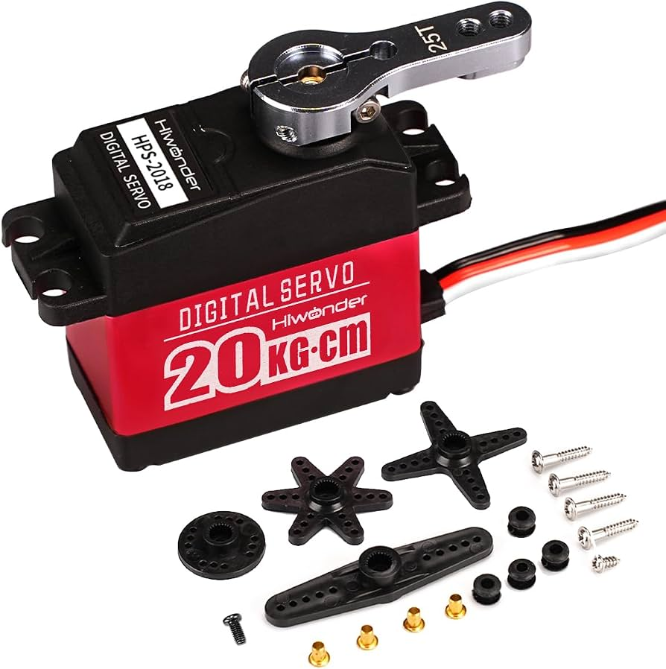
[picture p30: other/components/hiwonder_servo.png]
Hiwonder Servo
      <td align="center"></td>
      <td>
        • Torque: 20 kg·cm<br>
        • Metal Gears<br>
        • Fast Response
      </td>
      <td>Steering Actuation</td>
      <td>6.5V Regulated Power Rail (PWM Control)</td>
      <td>Metal gears and high torque ensure rigid steering alignment without mechanical backlash.</td>
    </tr>
    <tr>
      <td><b>ESP32 Dev Board</b></td>
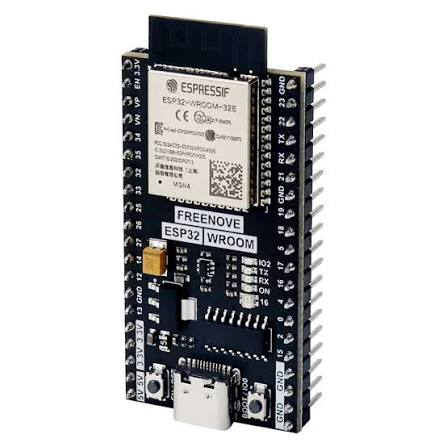
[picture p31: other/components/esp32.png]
ESP32 Board
      <td align="center"></td>
      <td>
        • Dual-Core 240MHz<br>
        • Wi-Fi / Bluetooth<br>
        • Hardware PWM
      </td>
      <td>Low-Level Microcontroller</td>
      <td>5V Regulated Logic Input (UART / I2C)</td>
      <td>High processing speed for real-time encoder readings and PID motor loops.</td>
    </tr>
    <tr>
      <td><b>BNO055 9-DOF IMU</b></td>
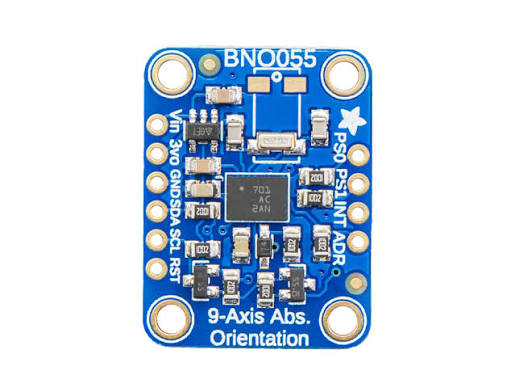
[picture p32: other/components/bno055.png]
BNO055 IMU
      <td align="center"></td>
      <td>
        • Onboard Sensor Fusion<br>
        • Absolute Orientation<br>
        • Low Drift
      </td>
      <td>Orientation Feedback</td>
      <td>ESP32 via I2C Bus</td>
      <td>Built-in sensor fusion algorithm offloads IMU filtering from the main MCU.</td>
    </tr>
    <tr>
      <td><b>Raspberry Pi 5</b></td>
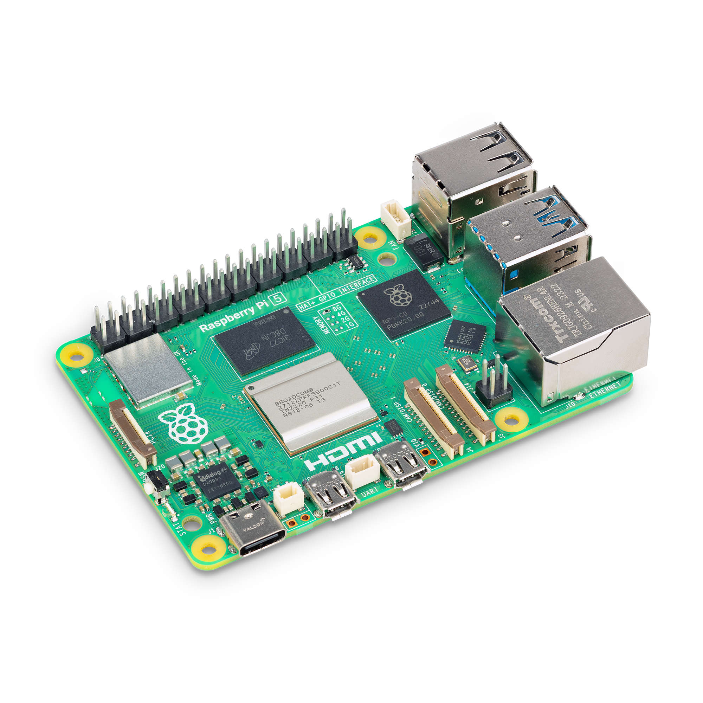
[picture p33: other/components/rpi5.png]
Raspberry Pi 5
      <td align="center"></td>
      <td>
        • Quad-Core ARM<br>
        • 16GB RAM<br>
        • USB 3.0
      </td>
      <td>High-Level Vision Processing</td>
      <td>5V Regulated Logic Rail (USB/UART Interface)</td>
      <td>Delivers high computational power and memory for real-time OpenCV image processing.</td>
    </tr>
    <tr>
      <td><b>Logitech Brio 100</b></td>
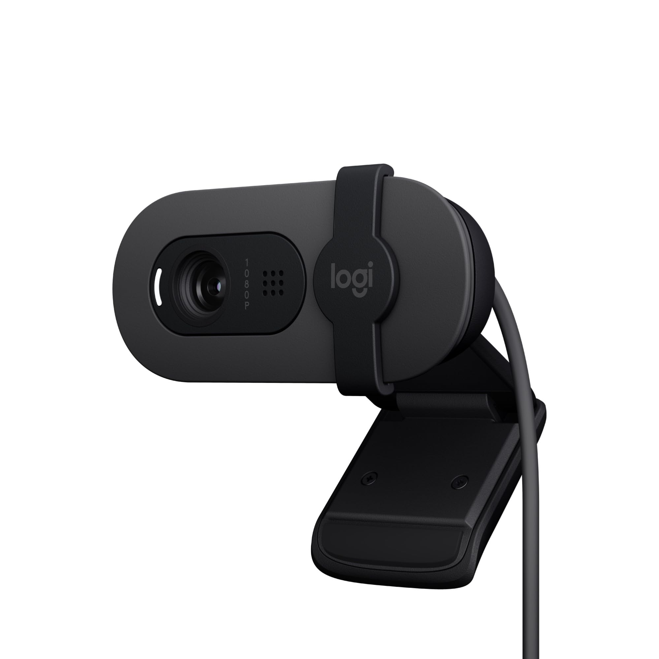
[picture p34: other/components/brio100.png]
Logitech Brio 100
      <td align="center"></td>
      <td>
        • 1080p Resolution<br>
        • Wide FOV<br>
        • Auto Light Balance
      </td>
      <td>Computer Vision Camera</td>
      <td>USB Connection to Raspberry Pi 5</td>
      <td>Provides high clarity and stable frame rates across varying ambient light conditions.</td>
    </tr>
    <tr>
      <td><b>XL4015 Buck Converters</b></td>
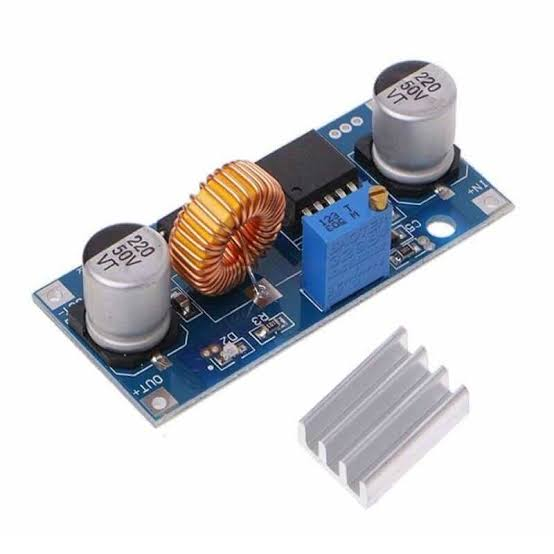
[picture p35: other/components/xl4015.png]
XL4015 Buck Converter
      <td align="center"></td>
      <td>
        • Max Output: 5A / 50W<br>
        • Adjustable Step-Down<br>
        • High Efficiency (>90%)
      </td>
      <td>Power Step-Down (Logic & Servo)</td>
      <td>Battery → Regulated Rails</td>
      <td>Drives logic circuits and servos efficiently with low heat dissipation.</td>
    </tr>
  </tbody>
</table>

---

### Strategic Component Placement (Physical Layout)

Component placement bridges our electrical schematic with the mechanical reality of the chassis. Positioning was dictated by three core constraints: **signal integrity (minimizing wire length)**, **electromagnetic interference (EMI) reduction**, and **accessibility for quick pit-stop maintenance**.

<p align="center">
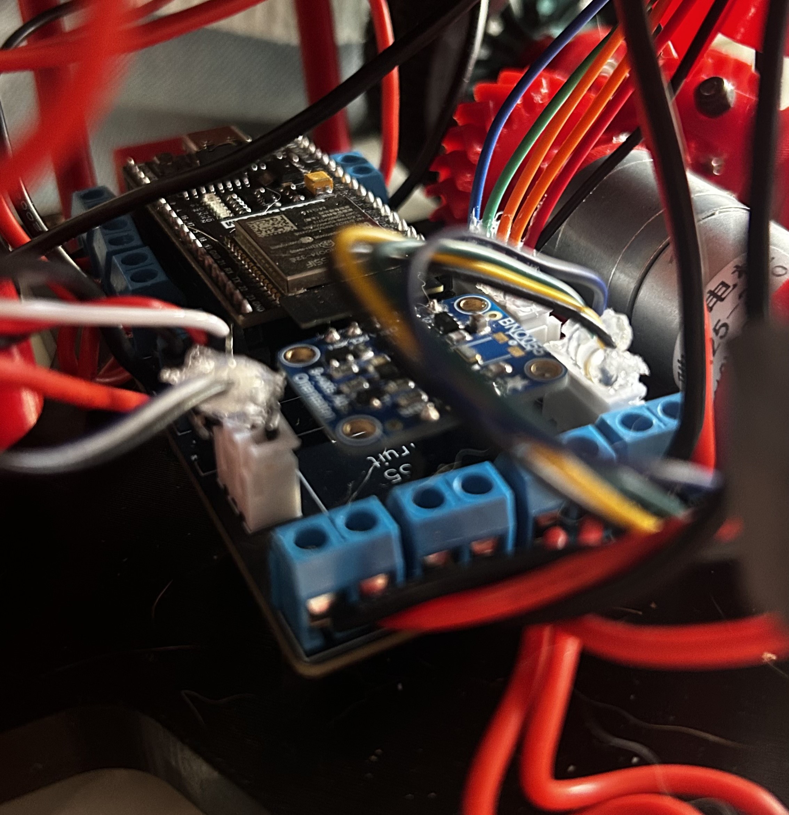
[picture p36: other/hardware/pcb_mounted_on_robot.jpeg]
Final PCB Integrated into Vehicle Chassis
  
  <br>
  <em>Final logic PCB physically mounted on the vehicle chassis.</em>
</p>

| **Component** | **Physical Placement** | **Engineering Rationale** |
| :--- | :--- | :--- |
| **ESP32 & BNO055 IMU** | Centered directly on carrier PCB | Keeps I²C / signal traces extremely short to prevent noise. Rigid PCB mounting ensures the IMU reads true chassis kinematics without vibration anomalies. |
| **BTS7960 Motor Driver** | Rear chassis, adjacent to motor | Keeps high-current motor wiring as short as possible, reducing voltage drop (I²R losses) and keeping inductive motor noise away from the logic boards. |
| **XL4015 Regulators** | Segregated near battery inputs | Steps down voltage immediately at the source, reducing unnecessary runs of raw 11.1V/7.4V lines across the chassis. |
| **Battery Connectors** | PCB outer edges | Ensures rapid, unobstructed access for battery hot-swapping between competition runs. |
| **Servo Header** | Accessible PCB perimeter | Allows for quick steering actuator replacement without needing to disassemble or unmount the entire logic board. |
| **Raspberry Pi 5** | Elevated deck, isolated from motors | Physically distances sensitive high-speed logic from motor EMI and provides better ambient airflow for CPU cooling. |

#### Sensor Kinematics & Field Geometry

Beyond electrical routing, sensor placement was strictly optimized to map the physical geometry of the WRO competition field accurately:

* **Camera (Perception & FOV):** Positioned at the highest frontal point to maximize look-ahead detection distance while eliminating structural blind spots. Its final pitch angle was empirically calibrated on the physical track to mitigate harsh overhead lighting reflections, floor shadows, and horizon distortion.
* **BNO055 IMU (Orientation):** Hard-mounted to perfectly align with the vehicle’s longitudinal axis. This precise orientation guarantees that yaw calculations reflect the chassis's true kinematic center without introducing angular offsets.
* **Quadrature Encoder (Odometry):** Mechanically coupled directly to the drive motor shaft. This 1:1 rigid coupling ensures that wheel rotation is translated into precise linear distance data, minimizing errors caused by mechanical backlash.

---

### Iterative Design Process

The final custom PCB was the result of a systematic iteration process. Before manufacturing the final board, the complete electrical system was assembled using temporary wire harnesses and tested directly on the physical robot chassis under dynamic loads. This allowed us to identify electrical bottlenecks and mechanical constraints before committing to a permanent copper layout.

<p align="center">
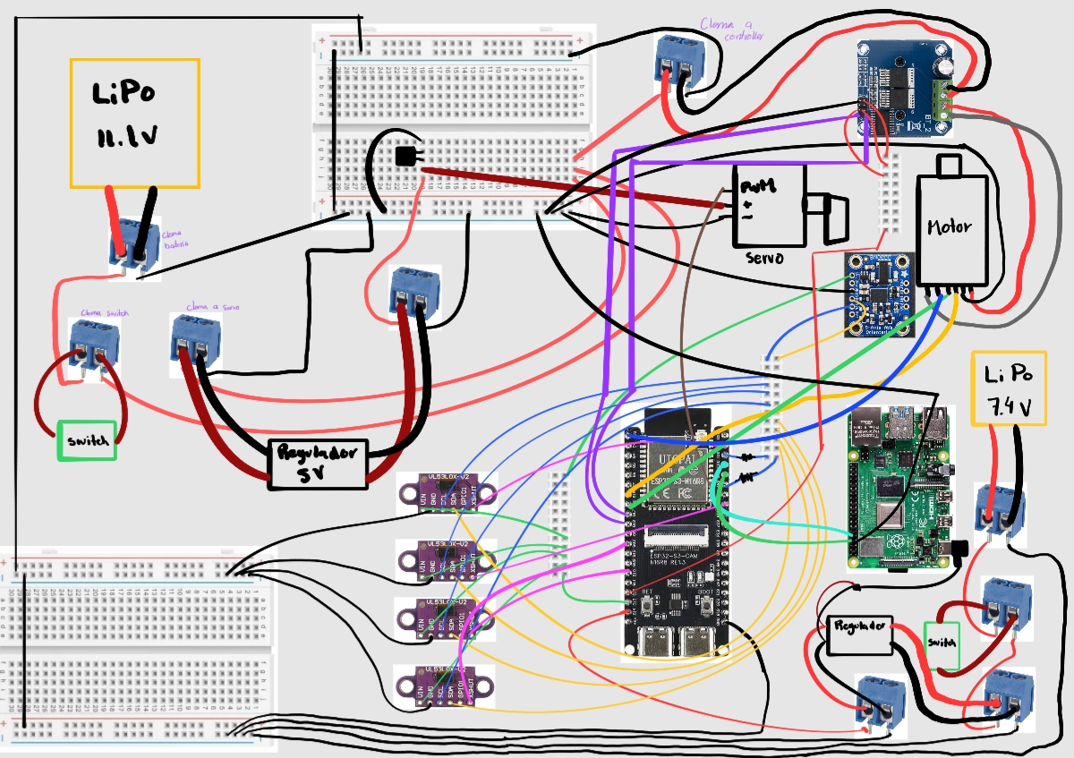
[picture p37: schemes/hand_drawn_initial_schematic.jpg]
Hand-drawn Initial Schematic
  
  &nbsp;&nbsp;
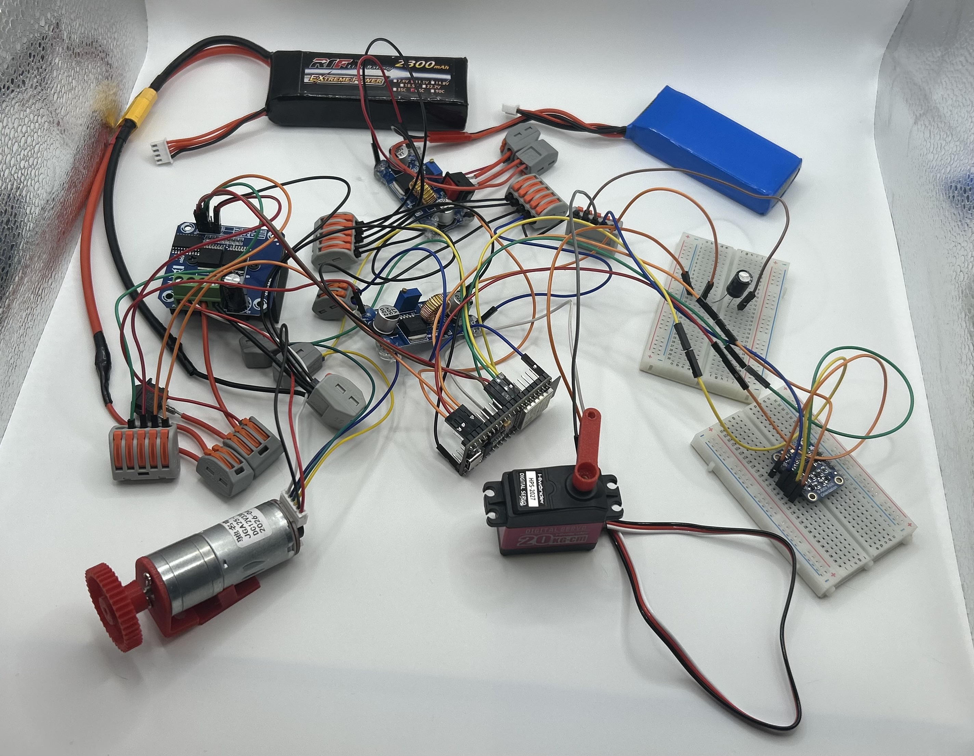
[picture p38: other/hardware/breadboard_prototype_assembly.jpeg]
Breadboard Prototype Assembly
  
  <br>
  <em>Left: Initial hand-drawn circuit mapping. Right: Breadboard logic validation before PCB design.</em>
</p>

#### Evolution of the Electrical Schematic

Our electrical mapping evolved to address noise constraints and incorporate dual battery isolation.

<p align="center">
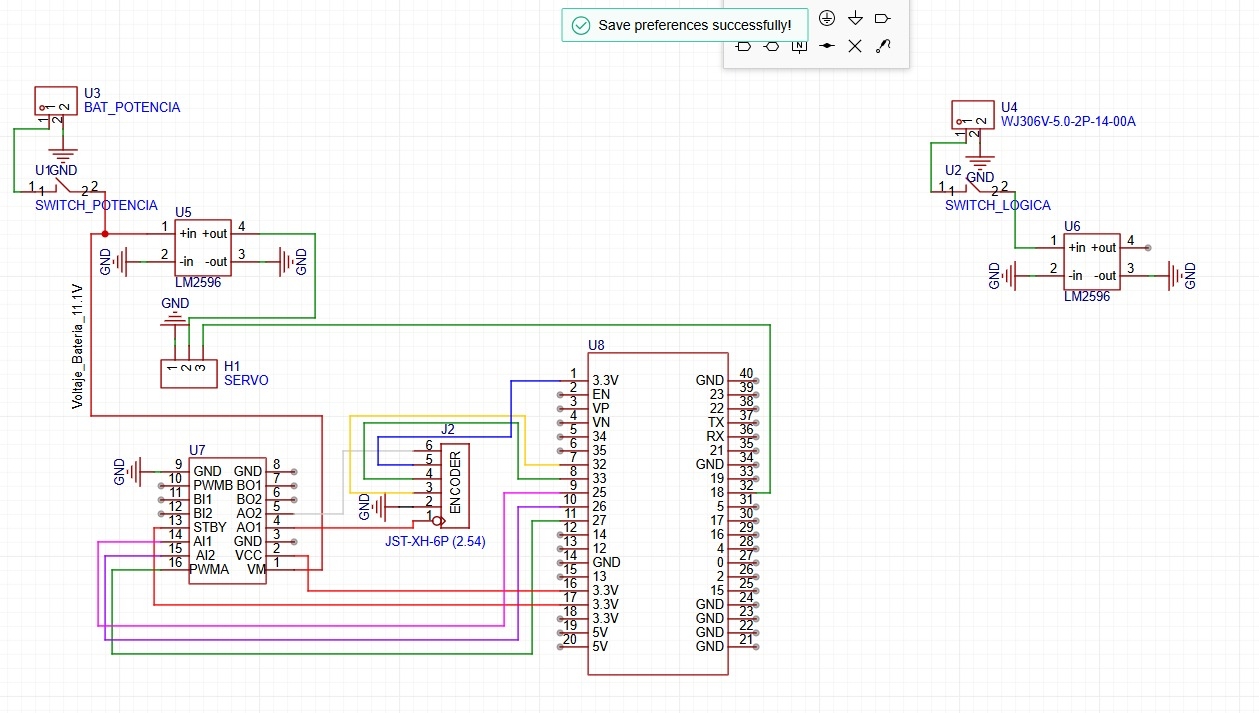
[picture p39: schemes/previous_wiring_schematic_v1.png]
Previous Wiring Schematic V1
  
  &nbsp;&nbsp;
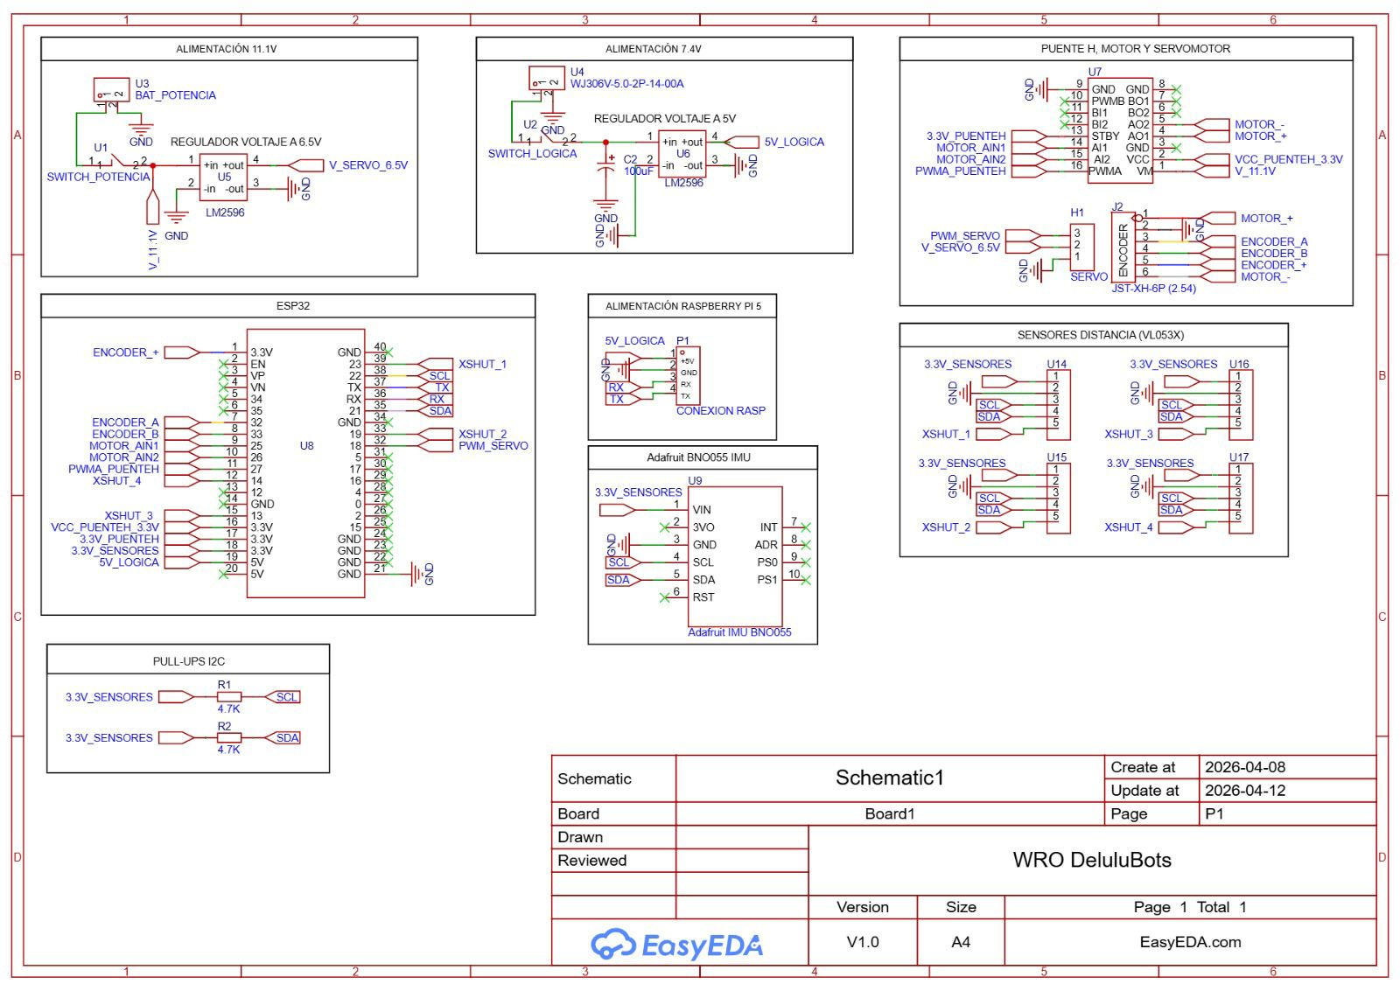
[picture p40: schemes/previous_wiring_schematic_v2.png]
Previous Wiring Schematic V2
  
  <br>
  <em>Earlier revisions of the system architecture (v1 and v2) during the prototyping phase.</em>
</p>

#### Hardware Iteration Matrix

| **Observation / Issue** | **Design Change Implemented** | **Expected Improvement** |
| :--- | :--- | :--- |
| **Spaghetti Wiring:** Loose temporary wires made connections fragile and difficult to organize. | **Custom Carrier PCB:** Designed a dedicated two-layer printed circuit board. | Achieved highly organized, vibration-resistant, and reproducible wiring. |
| **Brownouts:** Actuator loads (motors/servos) caused voltage drops affecting the Pi and ESP32. | **Dual-Domain Battery System:** Divided the system into two physically isolated battery domains. | Prevented MCU resets by physically decoupling logic from inductive loads. |
| **Voltage Risks:** Buck regulators required precise manual adjustment via potentiometers. | **Pre-Power Validation Step:** Enforced manual multimeter checks of XL4015 outputs before IC insertion. | Eliminated the risk of frying 5V logic lines with accidental 11V inputs. |
| **Human Error:** Standard pin headers allowed for accidental reverse polarity during battery swaps. | **Keyed Connectors:** Transitioned to XT60 and keyed JST connectors for power delivery. | Made it physically impossible to plug batteries in backward during the stress of competition. |
| **Signal Routing:** Multiple loose signal jumper wires were difficult to manage and trace. | **Centralized JST Headers:** Grouped signal lines into dedicated JST-XH headers on the PCB. | Faster assembly, easier module replacement, and simplified troubleshooting. |

---

### Custom PCB Design & Integration

The printed circuit board was engineered to transform the electrical ecosystem from a fragile prototype into a competition-ready, reproducible system. Rather than relying on independent wiring, the PCB acts as the central nervous system, providing dedicated power distribution planes, shielded signal traces, and secure component mounting.

<p align="center">
  Prototype PCB Iteration
  &nbsp;&nbsp;
  Final PCB 3D Model
  <br>
  <em>Left: Initial prototype board layout. Right: Final competition-ready custom PCB 3D model.</em>
</p>

#### PCB Architecture Decisions

| **Feature** | **Design Decision** | **Engineering Rationale** |
| :--- | :--- | :--- |
| **Structure** | Two-Layer PCB (FR4) | Provides adequate routing flexibility while keeping the board footprint compact. |
| **Grounding** | Common Ground Plane (Polygon Pour) | Ensures a unified electrical reference for control/communication, reducing ground loops. |
| **Power Distribution** | Dedicated Power Rails | Replaces unpredictable wire resistance with calculated copper paths, simplifying debugging. |
| **Motor Driver** | External BTS7960 Module | Offloads extreme thermal dissipation (up to 43A) away from the main PCB logic. |
| **ESP32 & IMU** | Direct PCB Surface Mounting | Minimizes I²C wire length for the BNO055, reducing noise and capacitance on the data lines. |
| **Power Inputs** | KF301-2P Terminals | Provides robust, high-current mechanical clamping for raw battery inputs. |

#### PCB Trace Width Optimization

To guarantee electrical safety and prevent copper delamination under heavy loads, trace widths were dynamically calculated rather than uniformly applied. 

Using standard **IPC-2221 design formulas**, we dimensioned the power traces based on expected temperature rise and current flow. Special attention was given to the actuator power paths: because the GM25 motor can hit a **stall current of up to 5.6 A**, those specific traces were significantly widened and reinforced with copper pours to ensure they can handle transient spikes without dangerous thermal buildup. Signal traces (like UART and I²C), which carry milliamperes, were kept thin to save routing space.

---

### Systematic Sensor Calibration Protocols

Systematic sensor calibration is conducted before executing autonomous runs to verify that all sensor readings reliably represent the vehicle's true physical state on the competition field.

| **Subsystem** | **Calibration Method** | **Validation Purpose** |
| :--- | :--- | :--- |
| **BNO055 IMU** | Stationary zero-bias initialization & axis verification | Establishes a true, drift-free angular heading reference. |
| **Motor Encoder** | Ground-truth linear translation measurement | Validates wheel ticks-to-distance odometry scaling factors. |
| **Logitech Brio Camera** | Visual pipeline tuning under ambient arena lighting | Maximizes detection accuracy, contrast, and color thresholding. |
| **Steering Servo** | Commanded PWM pulse width vs. physical steering angle | Eliminates mechanical backlash and ensures centered tracking. |

#### BNO055 Orientation Calibration
During bootup, the vehicle remains completely stationary for three seconds. This permits the onboard sensor fusion co-processor to zero its internal rate gyros, compute accelerometer gravity vectors, and establish an absolute zero heading aligned with the track direction.

#### Encoder Odometry Calibration
Odometry scaling factors are verified by commanding the vehicle to travel an exact distance measured physically on the field. Encoder counts are recorded over multiple iterations to determine the real-world pulse-to-distance conversion ratio, compensating for slight wheel diameter variations and tire compression.

#### Vision System & Environmental Lighting Calibration
Vision calibration verifies camera pitch, Field of View (FOV), exposure, and HSV color thresholds directly on the practice mat. The camera exposure is manually locked to prevent auto-adjusting shutter speeds under fluctuating venue lighting, preventing false line detections from floor glare and shadows.
## 4. Software

### 4.1. Computer Vision

#### HSV calibration

##### Overview

Reliable color detection is essential for autonomous navigation. Different lighting conditions can significantly alter the appearance of objects on the field, making fixed color values unsuitable.

To solve this problem, a calibration tool was developed to adjust and store HSV ranges for each element of the competition.

The tool allows users to tune the HSV thresholds in real time and immediately visualize the resulting mask.

---

##### Calibration Interface

The interface includes:

- HSV sliders.
- Real-time camera preview.
- Binary mask visualization.
- Configuration saving.

Each color can be adjusted independently.

---

##### Calibration Workflow

```text
┌──────────────────────────┐
│       Camera Frame       │
└────────────┬─────────────┘
             │
             ▼
┌──────────────────────────┐
│      HSV Conversion      │
└────────────┬─────────────┘
             │
             ▼
┌──────────────────────────┐
│  Threshold Adjustment    │
└────────────┬─────────────┘
             │
             ▼
┌──────────────────────────┐
│      Mask Preview        │
└────────────┬─────────────┘
             │
             ▼
┌──────────────────────────┐
│    Save Configuration    │
└──────────────────────────┘
```

---

##### HSV Color Space

The calibration system converts each frame from BGR to HSV:

```python
hsv = cv2.cvtColor(frame, cv2.COLOR_BGR2HSV)
```

HSV was selected because it separates color information from illumination, allowing the system to adapt more easily to different environments.

---

##### Mask Generation

The binary mask is generated using:

```python
mask = cv2.inRange(
    hsv,
    np.array(low),
    np.array(high)
)
```

Pixels inside the selected range are preserved, while all other pixels are discarded.

---

##### Configuration Storage

The calibrated HSV ranges are stored in:

```text
config/
└── saved_ranges.py
```

These values are later loaded by the vision pipeline and used during obstacle detection and navigation.

##### Detection Examples

###### Red Signs

Red Sign Calibration

---

###### Green Signs

Green Sign Calibration
---

###### Blue Lines

Blue line Calibration

---

###### Orange Lines

Orange line Calibration

---

###### Parking Walls

Pink Wall Calibration

---

###### White Space

White Space Calibration

#### Element detection

##### Overview

The computer vision system processes the images captured by the camera and detects the different elements present on the competition field.

The HSV ranges used by the detection algorithms are generated using the calibration tool described in [`calibration`](#hsv-calibration).

The system currently detects:

- Red signs.
- Green signs.
- Blue lines.
- Orange lines.
- Pink parking walls.
- Track space.

---

##### Vision Pipeline

```text
┌──────────────────────────┐
│       Camera Frame       │
└────────────┬─────────────┘
             │
             ▼
┌──────────────────────────┐
│      HSV Conversion      │
└────────────┬─────────────┘
             │
             ▼
┌──────────────────────────┐
│      Color Filtering     │
└────────────┬─────────────┘
             │
             ▼
┌──────────────────────────┐
│ Morphological Operations │
└────────────┬─────────────┘
             │
             ▼
┌──────────────────────────┐
│    Contour Detection     │
└────────────┬─────────────┘
             │
             ▼
┌──────────────────────────┐
│ Bounding Box Generation  │
└────────────┬─────────────┘
             │
             ▼
┌──────────────────────────┐
│     Target Selection     │
└──────────────────────────┘
```

---

##### Detection

The `process_elements()` method performs the detection process for signs and lines.

For each frame:

1. The image is converted to HSV.
2. A binary mask is generated.
3. Morphological operations remove noise.
4. Contours are extracted.
5. Small contours are discarded.
6. A target element is selected.

Each detected element stores:

- Color.
- Binary mask.
- Contour.
- Area.
- Bounding rectangle.

---

##### Sign Detection

Red and green signs are processed using:

```python
VisionUtils.select_target_pillar()
```

The selected target is determined according to:

1. Contour area.
2. Vertical position.

When both signs have similar areas, the sign located lower in the image is considered closer to the robot.

---

##### Line Detection

Blue and orange lines are processed using:

```python
VisionUtils.select_target_line()
```

Unlike signs, line detection prioritizes the vertical position because perspective distortion affects their apparent size.

If both lines are located at similar heights, contour area is used as a secondary criterion.

---

##### Track Detection

Track detection uses a different pipeline.

Before processing, red and green objects are replaced to avoid interference:

```python
image = VisionUtils.replace_color(
    frame,
    saved_ranges.color_ranges,
    ["Red", "Green"]
)
```

The image then follows the following steps:

```text
┌──────────────────────────┐
│          Resize          │
└────────────┬─────────────┘
             │
             ▼
┌──────────────────────────┐
│   Grayscale conversion   │
└────────────┬─────────────┘
             │
             ▼ 
┌──────────────────────────┐
│    Bilateral filtering   │
└────────────┬─────────────┘
             │
             ▼    
┌──────────────────────────┐
│       Thresholding       │
└────────────┬─────────────┘
             │
             ▼       
┌──────────────────────────┐
│  Morphological closing   │
└────────────┬─────────────┘
             │
             ▼    
┌──────────────────────────┐
│     Largest countour     |
|        extraction        │
└──────────────────────────┘
```

The largest valid contour is preserved and used as the track representation.

---

##### Software Structure

```text
ImageManager
    │
    ├── process_walls()
    ├── process_elements()
    ├── show_results()
    ├── run_test()
    └── run_test_from_image()

VisionUtils
    │
    ├── detect_element()
    ├── select_target_pillar()
    ├── select_target_line()
    ├── draw_element()
    ├── keep_largest_white()
    └── replace_color()
```

### 4.2. Vehicle Control

#### Obstacle challenge logic
#### Lap counting
#### Parking procedure

## 5. DIY Game Field

Field Overview

To test our autonomous vehicle under conditions closer to the actual competition, we decided to build our own full-scale game field. Having a field available for regular testing allowed us to work on autonomous navigation, computer vision, obstacle detection, and parking. Our goal was to build a field that followed the main WRO specifications while keeping it affordable, reusable, and easy to modify between tests.

---

### Materials and Budget

The total estimated cost was approximately **$50.84 USD**.

| Material | Qty | Cost (USD) | Store / Reference Link |
| :--- | :--- | :--- | :--- |
| **White Tarpaulin** (3x3m min) | 1 | $17.58 | [MercadoLibre](https://www.mercadolibre.com.mx/pared-de-3-lados-9m-para-carpa-toldo-3x3-impermeable-uv-blanco/p/MLM51398001) |
| **3mm MDF Panel** (1.22 x 2.44m) | 1 | $9.73 | [Home Depot](https://www.homedepot.com.mx/p/arauco-panel-de-mdf-3-mm-122-x-244-m-arauco-trupan-286133) |
| **Matte Black Paint for Wood** (1L) | 1 | $6.19 | Local Hardware Store |
| **Panduit ST17 Orange Tape** | 1 | $3.83 | [MercadoLibre](https://www.mercadolibre.com.mx/cinta-aislante-panduit-naranja-st17-075-66or-pvc-2012m-x-19mm/p/MLM47125027) |
| **TUK Vinyl Blue Tape** | 1 | $1.30 | [Home Depot](https://www.homedepot.com.mx/p/tuk-cinta-aislante-electrica-de-vinilo-19-mm-x-18-m-az-345325-121543) |
| **Acrylic Paint** (Magenta, Red, Green)| 3 | $6.90 | Office Depot |
| **Grey Sharpie Marker** | 1 | $1.89 | Office Depot |
| **Paint Roller & 1" Foam Brush** | 2 | $3.42 | Local Hardware Store / Home Depot |

> **Budget Tip:** We got our tarpaulin for free from a local print shop that was discarding it, so it's worth asking around before buying new.
---

### Step-by-Step Construction Guide

Each part of the field was designed to be inexpensive, easy to assemble, and reusable for future testing.

#### 1. Base Mat

The official field has an inner playing area of **3000 × 3000 mm**. We used a white tarpaulin as the base surface because it was inexpensive, easy to handle, and easy to store after testing.

---

#### 2. Exterior and Interior Walls

Exterior Walls Joints

> **Material:** 3 mm MDF  
> **Height:** 100 mm  
> **Color:** Matte black

**Exterior Walls**

Since the MDF sheet is 2440 mm long and the required wall length is 3000 mm, each exterior wall was divided into two **1500 mm sections**.

The sections were connected using custom wooden puzzle joints glued to the back of the panels. The same method was used to secure the 90-degree corners.

*This allowed us to achieve the required wall length without needing a larger MDF sheet.*

**Interior Walls**

The interior walls were built as modular segments so they could be rearranged for different configurations. All interior-facing walls were painted matte black.

Because the MDF is 3 mm thick, the short segments were reduced by **2 × 3 mm** to account for the thickness of the perpendicular walls:

| Segment | Quantity | Length |
|---|---:|---:|
| Long | 2 | 1000 mm |
| Long | 2 | 1400 mm |
| Long | 2 | 1800 mm |
| Short | 2 | 994 mm |
| Short | 2 | 1394 mm |
| Short | 2 | 1794 mm |

---

#### 3. Traffic Signs & Parking Delimiters

Pillars Construction

We used leftover 3 mm MDF from the wall construction to build both the traffic signs and parking delimiters as hollow structures. This reduced material usage while keeping the required external dimensions.

**Traffic Signs**

**50 × 50 × 100 mm** · **3 mm MDF** · **Red / Green**

**Cut list per sign:**
- 4 × 100 × 50 mm rectangles
- 2 × 50 × 50 mm caps

**Parking Delimiters**

**200 × 20 × 100 mm** · **3 mm MDF** · **Magenta**

**Cut list per delimiter:**
- 2 × 200 × 100 mm rectangles
- 2 × 20 × 100 mm rectangles
- 2 × 200 × 20 mm caps

> **Important:** When calculating the pieces for the hollow structures, account for the 3 mm MDF thickness to keep the final dimensions correct.

---

#### 4. Lines and Markings

The field requires **20 mm orange and blue lines**, along with thinner grey markings for the starting areas.

We initially tried painting the colored lines directly onto the tarpaulin, but the paint bled through the fabric. We switched to electrical tape instead:

- **Orange:** Panduit ST17
- **Blue:** TUK Vinyl Tape
- **Width:** close to the required 20 mm

The tape provided cleaner and more consistent lines, which was particularly important for our computer vision system.

The smaller markings and starting zones were measured and drawn manually using a ruler and grey Sharpie.

> **Design choice:** Electrical tape gave us cleaner edges and more consistent line widths than paint, making the field markings easier for our computer vision system to detect.

---

### Construction Process Gallery

| Process 1 | Process 2 |
| :---: | :---: |
| **1.** Cutting MDF strips and assembling the exterior wall joints. | **2.** Preparing the modular interior wall segments. |
| Process 3 | Process 4 |
| **3.** Building and painting the traffic signs and parking delimiters. | **4.** Measuring and applying the field lines and markings. |

The finished field became part of our regular testing setup, giving us a consistent environment to test changes to the robot and compare their results.

## 6. License

```text
MIT License

Copyright (c) 2026 Delulubots

Permission is hereby granted, free of charge, to any person obtaining a copy
of this software and associated documentation files (the "Software"), to deal
in the Software without restriction, including without limitation the rights
to use, copy, modify, merge, publish, distribute, sublicense, and/or sell
copies of the Software, and to permit persons to whom the Software is
furnished to do so, subject to the following conditions:

The above copyright notice and this permission notice shall be included in all
copies or substantial portions of the Software.

THE SOFTWARE IS PROVIDED "AS IS", WITHOUT WARRANTY OF ANY KIND, EXPRESS OR
IMPLIED, INCLUDING BUT NOT LIMITED TO THE WARRANTIES OF MERCHANTABILITY,
FITNESS FOR A PARTICULAR PURPOSE AND NONINFRINGEMENT. IN NO EVENT SHALL THE
AUTHORS OR COPYRIGHT HOLDERS BE LIABLE FOR ANY CLAIM, DAMAGES OR OTHER
LIABILITY, WHETHER IN AN ACTION OF CONTRACT, TORT OR OTHERWISE, ARISING FROM,
OUT OF OR IN CONNECTION WITH THE SOFTWARE OR THE USE OR OTHER DEALINGS IN THE
SOFTWARE.

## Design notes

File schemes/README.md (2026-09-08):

### Electrical Schemes

This folder contains the electrical schematics developed throughout the construction of our **WRO Future Engineers 2026 vehicle**.

Instead of documenting only the final circuit, we kept the previous versions to show how our wiring architecture evolved through **planning, testing, troubleshooting, and refinement**.

### From Idea to Final Design

Our electrical design started with a simple hand-drawn schematic and was progressively updated as components were tested and integrated into the physical robot.

The different versions represent the main stages of this process:

| Stage | Schematic | Purpose |
| --- | --- | --- |
| **01 — Initial Design** | `hand_drawn_initial_schematic.jpg` | First connection plan and identification of the main electrical components. |
| **02 — Wiring V1** | `previous_wiring_schematic_v1.png` | First digital representation of the prototype wiring. |
| **03 — Wiring V2** | `previous_wiring_schematic_v2.png` | Updated connections after physical testing and design changes. |
| **04 — Current Design** | `current_wiring_schematic.png` | Final wiring configuration used for the vehicle integration. |

### 01 — Initial Design

Our first approach was a hand-drawn schematic used to plan the main connections before assembling the electrical system.

<p align="center">
  
</p>

### 02 — Wiring V1

The first digital schematic translated the initial concept into a more structured representation of the prototype wiring.

<p align="center">
  
</p>

### 03 — Wiring V2

After testing the prototype, we updated the schematic to reflect changes in the power distribution, component connections, and signal routing.

<p align="center">
  
</p>

### 04 — Current Wiring Schematic

This is the current version of our electrical wiring design. It represents the configuration used during the final integration of the vehicle and serves as a reference for assembly and troubleshooting.

<p align="center">
  
</p>

### Design Evolution

Keeping the different schematic versions allowed us to document our design decisions instead of only presenting the final result.

Through this process, we were able to:

* Organize the power and signal connections.
* Identify and correct wiring problems during testing.
* Improve component accessibility and maintenance.
* Refine the electrical architecture before final PCB integration.
* Keep a clear reference for future modifications and troubleshooting.

### Documentation Structure

The **main README** explains the complete power and sensor architecture, including component selection, power distribution, sensor placement, calibration, PCB integration, and testing.

This folder focuses specifically on the **electrical schematics and their evolution**, providing the detailed connection references used throughout the development of the vehicle.

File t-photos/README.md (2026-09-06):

Team's photos
====
This folder captures the people and moments behind **DeluluBots**, from the memories we created together to the individuals who brought our WRO Future Engineers project to life.

## Photo Collection

- `team_official.jpg`: Official portrait of the DeluluBots team.

- `team_fun1.jpg`, `team_fun2.jpg`, `team_fun3.jpg`, `team_fun4.jpg`: A collection of informal and memorable moments shared by the team throughout our robotics journey.

- `member_student1.jpg`: Portrait of **Jesús Morales**, Mechanical & CAD Designer and Software Developer.

- `member_student2.jpg`: Portrait of **Saori Jasso**, Electronics, PCB Designer, and Software Developer.

- `member_coach.jpg`: Portrait of **Kevin Rucoba**, our team coach.

> **A team is more than the robot we build.** These photos capture the people, challenges, laughter, and experiences that made our journey as DeluluBots meaningful.

**Last updated:** September 2026

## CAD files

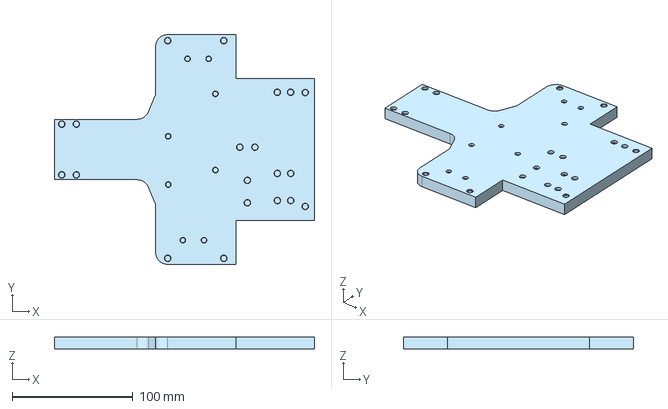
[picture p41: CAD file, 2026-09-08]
models/BasePlaque.step
215.0 x 190.0 x 10.0 mm

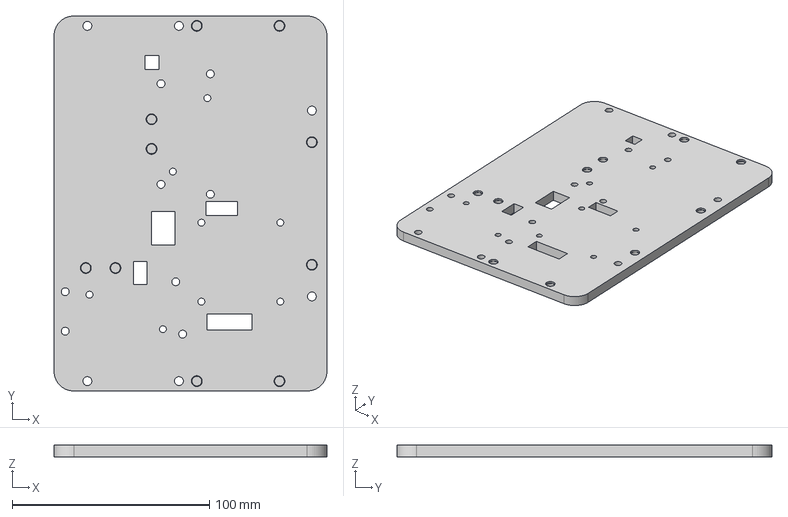
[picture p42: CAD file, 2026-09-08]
models/MiddlePlaque.step
138.3 x 190.0 x 6.00 mm

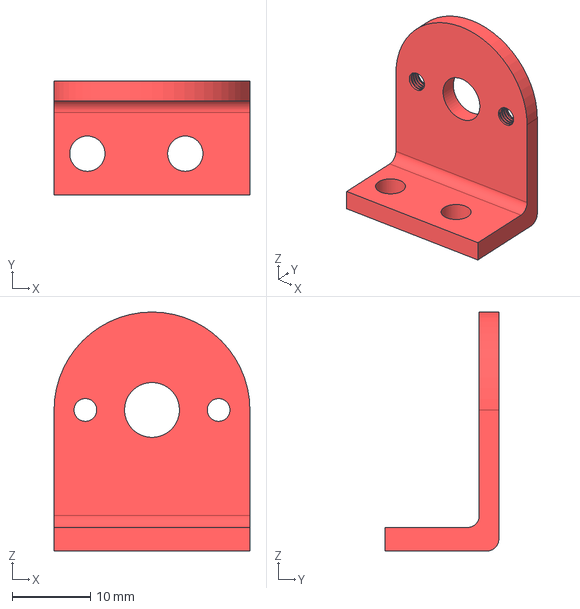
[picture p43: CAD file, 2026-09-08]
models/MotorRighHoldert.step
25.0 x 14.5 x 30.5 mm

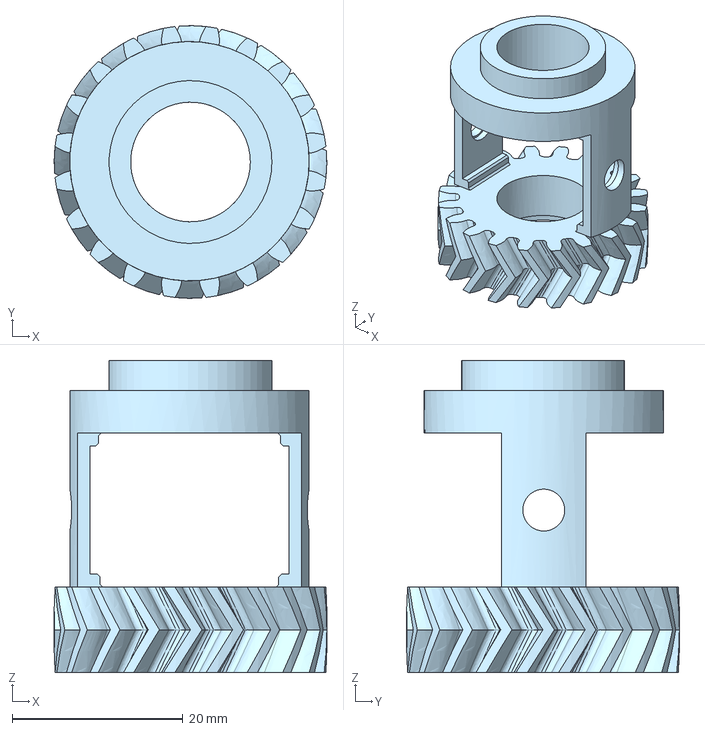
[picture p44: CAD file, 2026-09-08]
models/GearDifferential.step
31.9 x 31.9 x 36.5 mm

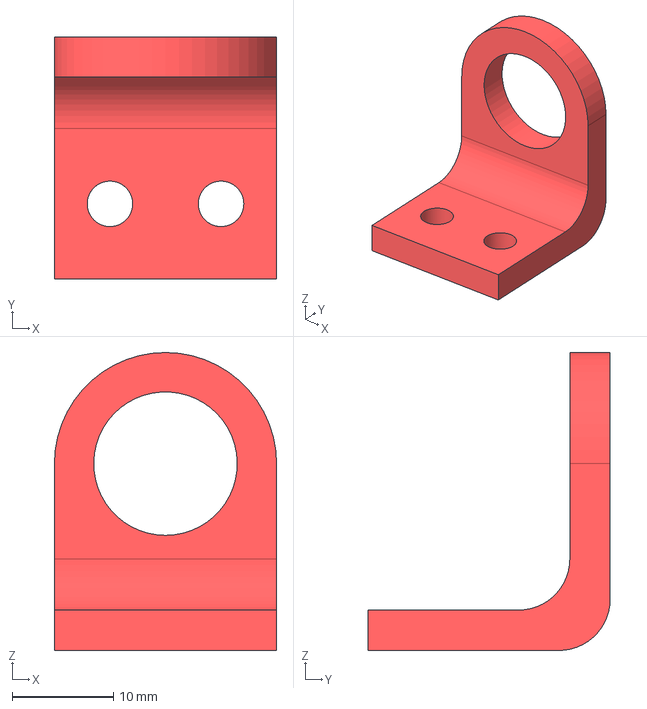
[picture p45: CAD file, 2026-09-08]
models/AxleSupportBracket.step
22.0 x 24.0 x 29.5 mm

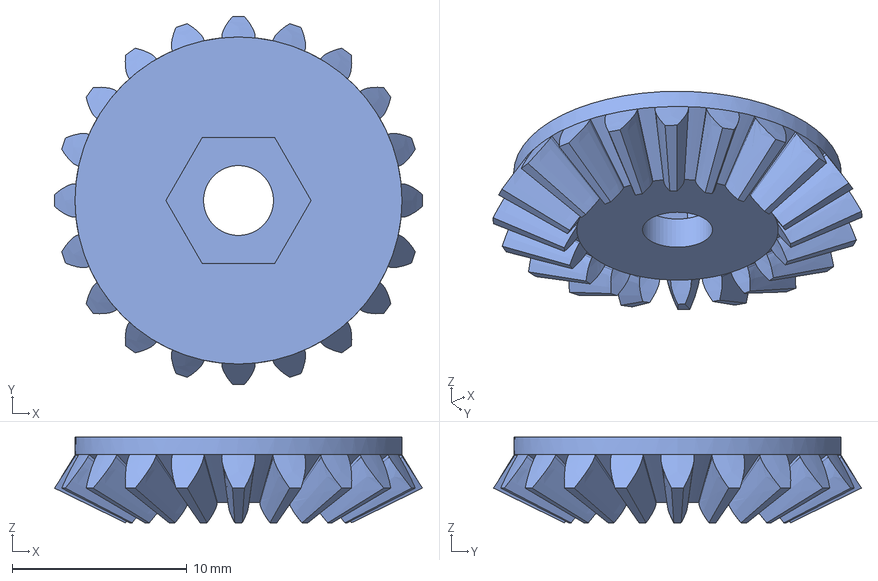
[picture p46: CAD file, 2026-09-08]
models/DifferentialSideGear.step
21.1 x 21.1 x 4.91 mm

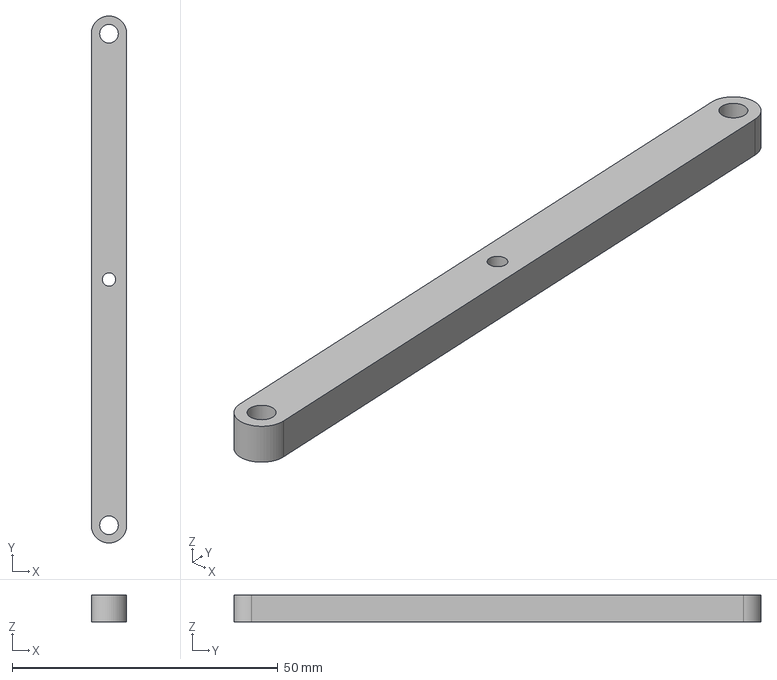
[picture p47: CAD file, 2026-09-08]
models/SteeringRod.step
6.68 x 99.1 x 5.00 mm

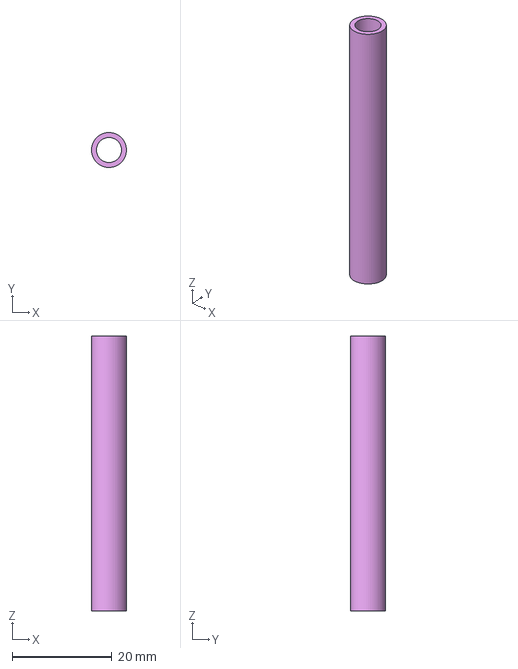
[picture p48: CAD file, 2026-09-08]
models/Standoff.step
6.99 x 7.00 x 55.0 mm

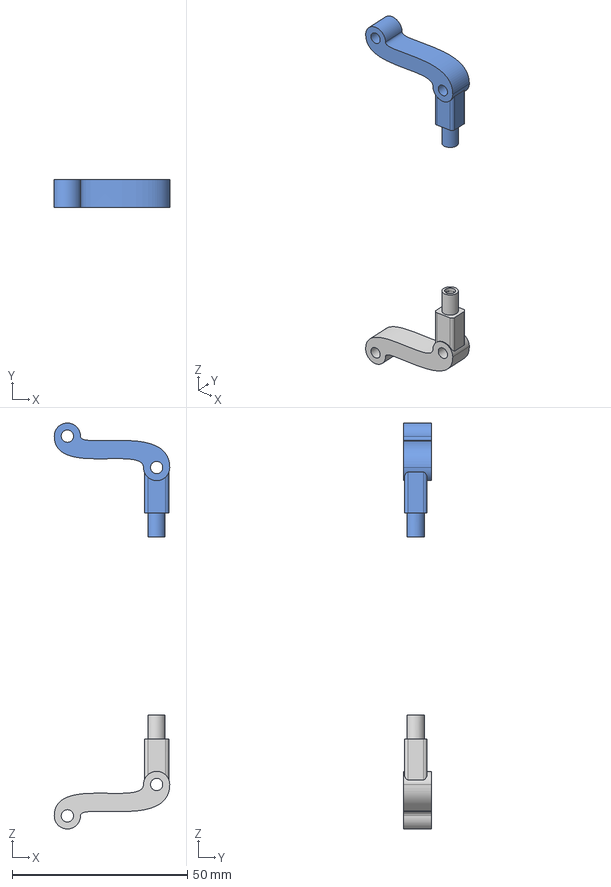
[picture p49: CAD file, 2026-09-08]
models/RightSteeringArm.step
33.0 x 8.02 x 115.9 mm

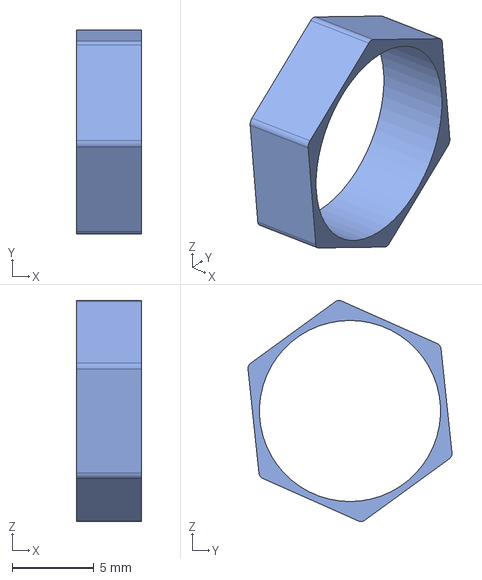
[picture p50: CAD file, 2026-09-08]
models/BearingAdapter.step
4.00 x 12.5 x 13.5 mm

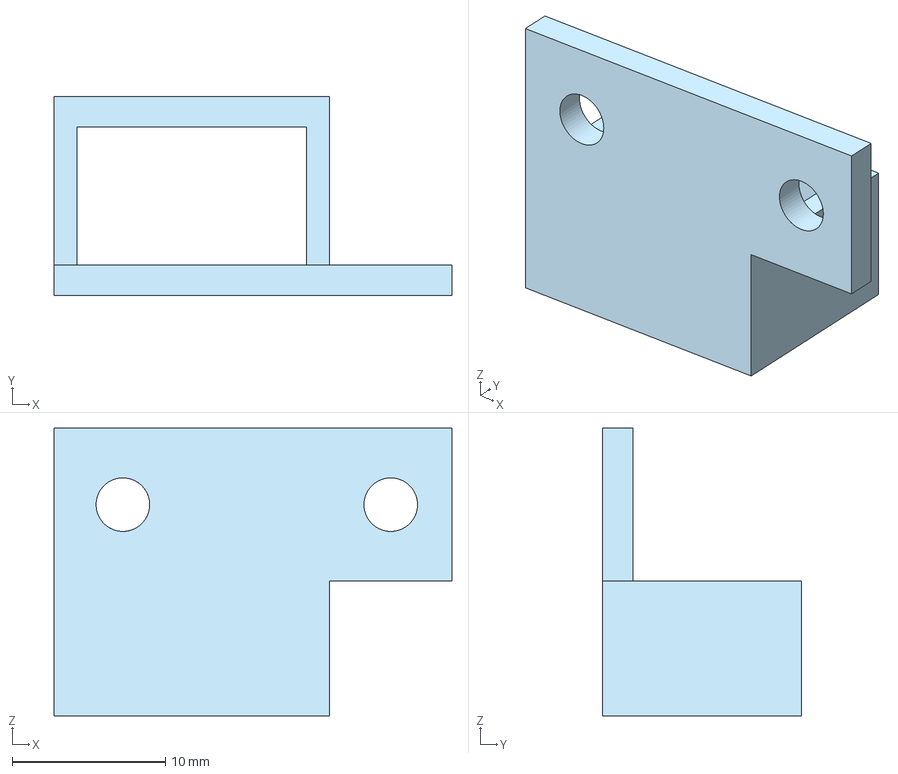
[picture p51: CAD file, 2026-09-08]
models/SwitchHolder.step
26.0 x 13.0 x 18.8 mm

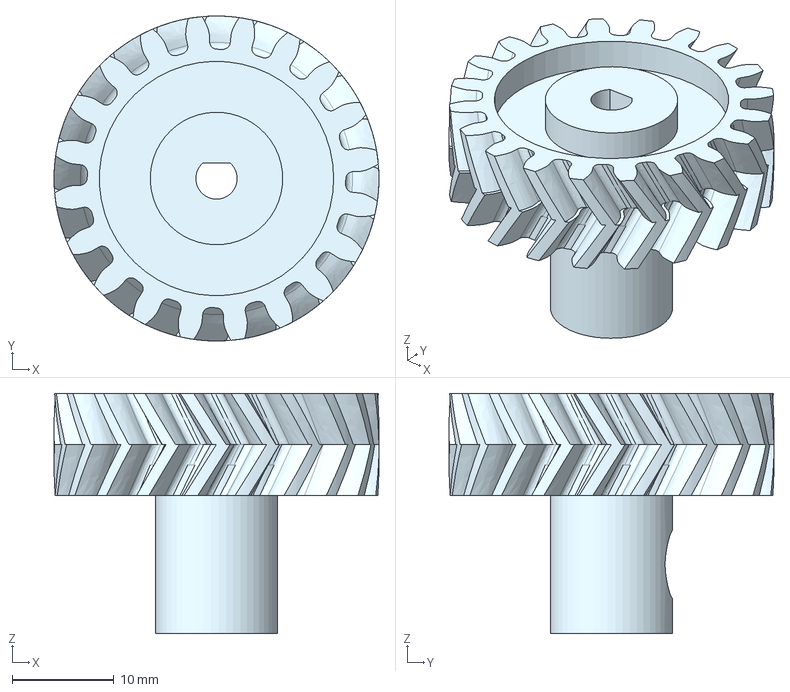
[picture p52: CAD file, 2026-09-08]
models/MotorGear.step
31.9 x 31.9 x 23.6 mm

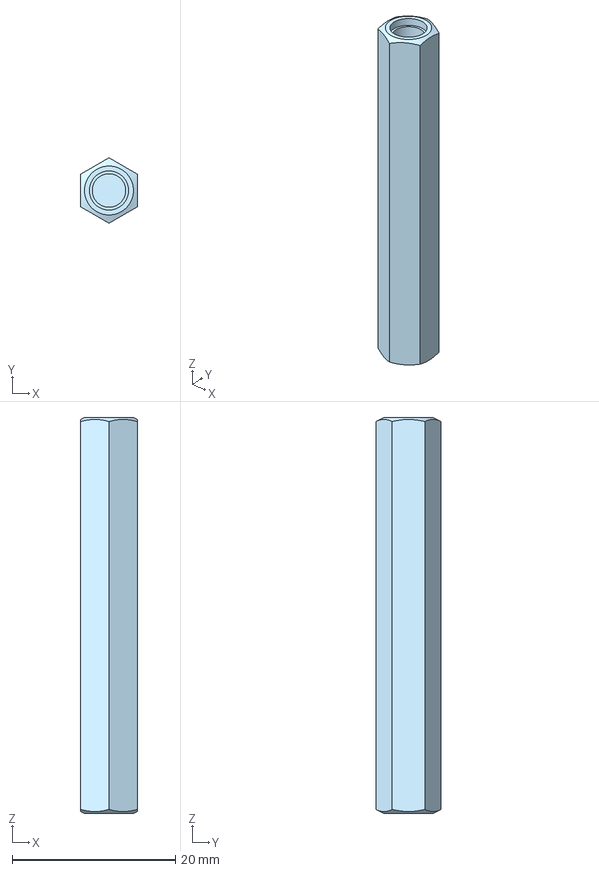
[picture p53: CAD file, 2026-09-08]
models/ShortAxle.step
6.94 x 8.01 x 48.5 mm

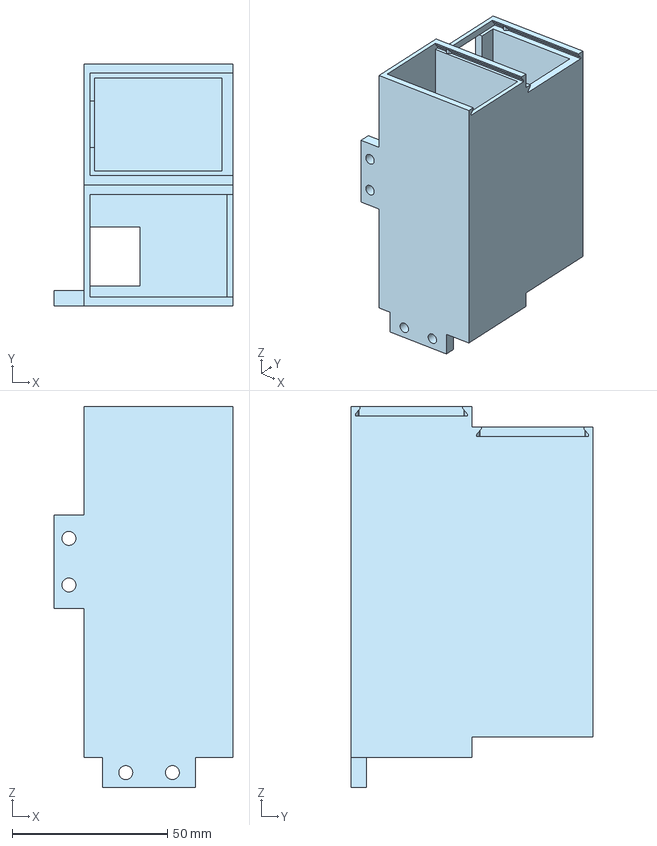
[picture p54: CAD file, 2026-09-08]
models/BatteryHolder.step
57.6 x 78.0 x 122.6 mm

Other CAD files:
models/WheelToAxleAdapter.step
models/StandoffExtension.step
models/MotorLeftHolder.step
models/LeftSteeringArm.step
models/AxleSupportBracket.stl
models/BasePlaque.stl
models/BatteryCover.step
models/BatteryCover.stl
models/BatteryHolder.stl
models/BearingAdapter.stl
models/CameraHolder.step
models/CameraHolder.stl
models/DifferentialSideGear.stl
models/DifferentialSpiderGear.step
models/DifferentialSpiderGear.stl
models/DoubleAxleSupportBracket.step
models/DoubleAxleSupportBracket.stl
models/GearDifferential.stl
models/LeftSteeringArm.stl
models/LongAxle.step
models/LongAxle.stl
models/MiddlePlaque.stl
models/MotorGear.stl
models/MotorLeftHolder.stl
models/MotorRighHoldert.stl
models/RightSteeringArm.stl
models/ServoHolder.step
models/ServoHolder.stl
models/ServoHorn.step
models/ServoHorn.stl
models/ShortAxle.stl
models/Standoff.stl
models/StandoffExtension.stl
models/SteeringRod.stl
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

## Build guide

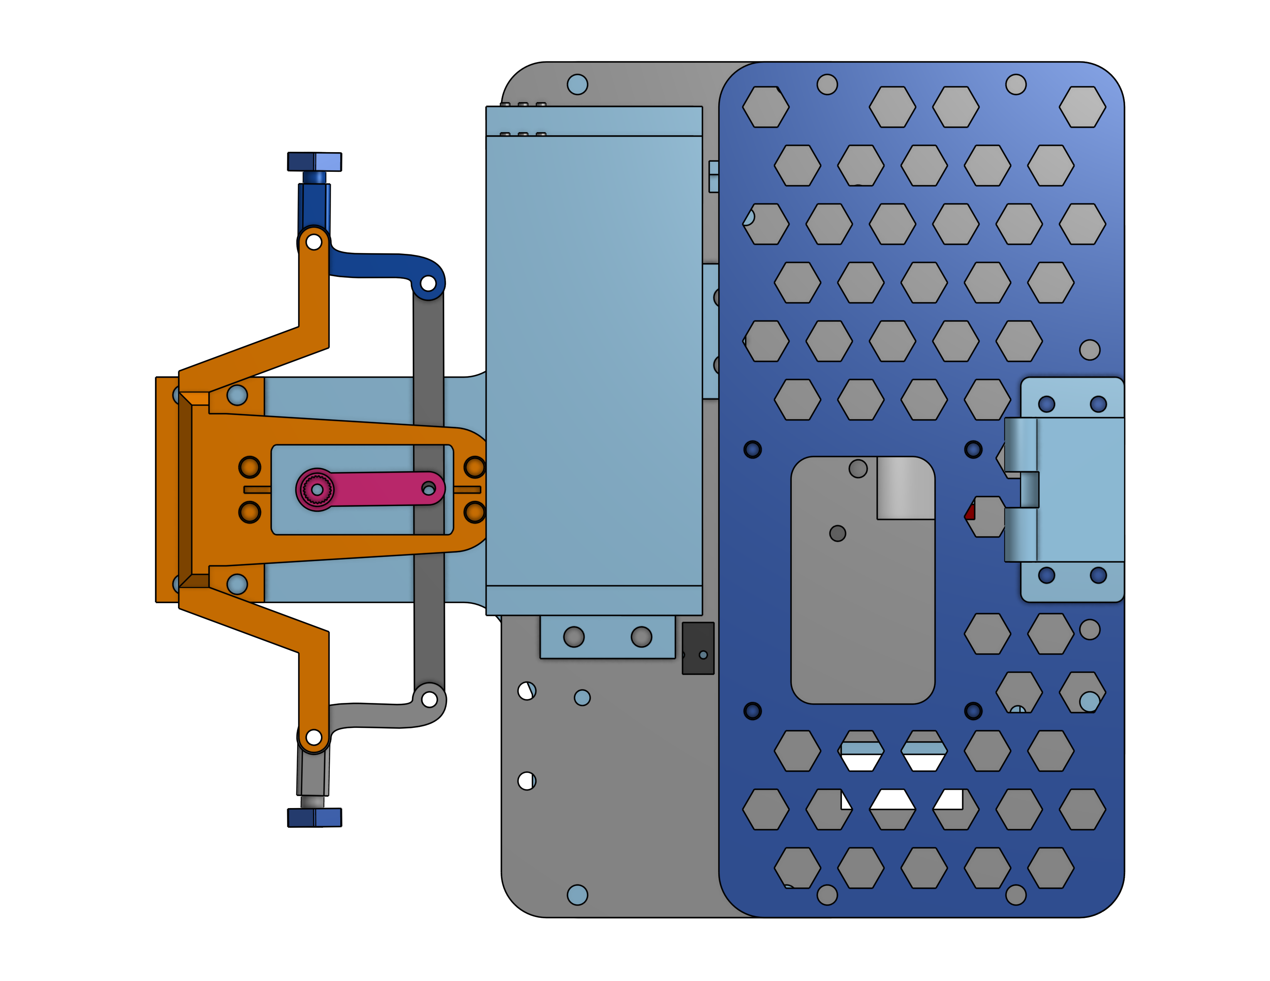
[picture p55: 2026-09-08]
models/RobotAssemblyTop.png

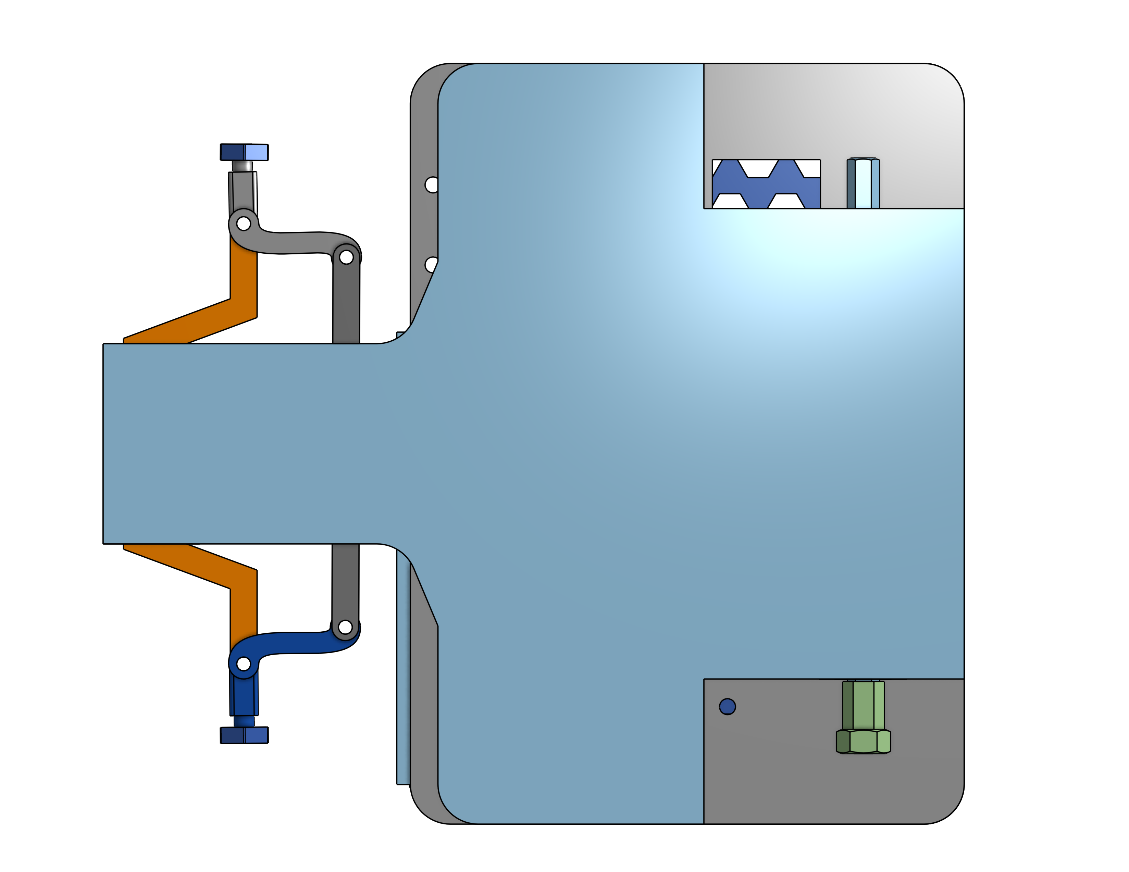
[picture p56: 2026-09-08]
models/RobotAssemblyBottom.png

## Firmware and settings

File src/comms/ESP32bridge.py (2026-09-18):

import serial
import time

class ESP32Bridge:
    def __init__(self, port='/dev/ttyAMA0', baudrate=115200, timeout=1):
        """Initializes the UART serial connection with the ESP32."""
        self.port_name = port
        self.baudrate = baudrate
        self.timeout = timeout
        self.ser = None
        self.connect()

    def connect(self):
        """Establishes connection and flushes serial buffers."""
        try:
            self.ser = serial.Serial(self.port_name, self.baudrate, timeout=self.timeout)
            self.ser.reset_input_buffer()
            self.ser.reset_output_buffer()
            print(f"[Serial] Connected to ESP32 on {self.port_name}")
        except serial.SerialException as e:
            print(f"[Serial Error] Could not open port {self.port_name}: {e}")
            self.ser = None

    def send_target_heading(self, target_yaw: float, is_corner: bool = False):
        """Sends target heading angle directly to the ESP32 via UART."""
        if self.ser and self.ser.is_open:
            # Formato ultra-simple: solo el valor flotante y salto de línea (ej: "45.5\n")
            message = f"{target_yaw:.1f}\n"
            try:
                self.ser.write(message.encode('utf-8'))
            except serial.SerialException as e:
                print(f"[Serial Error] Failed to send data: {e}")

    def read_current_yaw(self):
        """Reads every pending line and returns the most recent valid yaw."""
        if not (self.ser and self.ser.is_open):
            return None

        latest = None
        while self.ser.in_waiting > 0:
            try:
                line = self.ser.readline().decode("utf-8").strip()
                if line:
                    latest = float(line)
            except (ValueError, UnicodeDecodeError):
                continue
        return latest

    def close(self):
        """Closes the serial port gracefully."""
        if self.ser and self.ser.is_open:
            self.ser.close()
            print("[Serial] Port closed.")

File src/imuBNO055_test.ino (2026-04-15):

#include <Wire.h>                // I2C communication library
#include <Adafruit_Sensor.h>    // Base sensor structures
#include <Adafruit_BNO055.h>    // BNO055 sensor library
#include <utility/imumaths.h>   // Math utilities for orientation data

// Create BNO055 object with ID 55 and default I2C address (0x28)
Adafruit_BNO055 bno = Adafruit_BNO055(55, 0x28);

void setup(void) 
{
  Serial.begin(115200);   // Initialize serial communication for debugging
  delay(1000);            // Short delay to allow system startup

  // Initialize I2C communication on ESP32
  // SDA = GPIO 21, SCL = GPIO 22 (standard pins)
  Wire.begin(21, 22);

  Serial.println("BNO055 Test - ESP32");
  Serial.println("");

  // Attempt to initialize the sensor
  // If it fails, stop execution here
  if(!bno.begin())
  {
    Serial.println("BNO055 not detected. Check wiring or I2C address.");
    while(1); // Infinite loop to prevent further execution
  }

  delay(1000); // Allow sensor to stabilize

  // Enable external crystal for better accuracy
  bno.setExtCrystalUse(true);

  Serial.println("Sensor initialized successfully!");
}

void loop(void) 
{
  sensors_event_t event;   // Structure to store sensor data
  
  // Get a new orientation reading
  bno.getEvent(&event);

  // Print orientation data in degrees
  // X = Yaw (heading)
  // Y = Pitch (forward/backward tilt)
  // Z = Roll (side tilt)
  Serial.print("X (Yaw): ");
  Serial.print(event.orientation.x, 4);

  Serial.print("\tY (Pitch): ");
  Serial.print(event.orientation.y, 4);

  Serial.print("\tZ (Roll): ");
  Serial.print(event.orientation.z, 4);

  Serial.println(""); 

  delay(100); // Small delay to avoid flooding the serial monitor
}

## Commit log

2026-04-15 Add files via upload
    Added BNO055 IMU setup and orientation reading for navigation system
2026-05-04 Add color calibration module
2026-05-20 refactor(vision): restructure calibrator from structured to OOP
2026-05-21 feat(vision): add track polygon detection pipeline
2026-08-26 Add DIY_Field_Photos directory for track documentation
    Includes a .gitkeep file to establish the folder hierarchy before uploading the DIY track assembly images.
2026-08-27 docs: add DIY game field construction guide
    Adds the DIY field documentation to the README:
    - Includes full Bill of Materials (BOM).
    - Details custom MDF puzzle joints and modular walls.
    - Explains material choices.
    - Sets up image placeholders for the v-photos/ directory.
2026-09-07 docs: update power and sense management section in README
2026-09-08 docs(hardware): update README and add CAD files and photos
    [AxleSupportBracket.step, AxleSupportBracket.stl, BasePlaque.step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]
2026-09-08 docs(hardware): add power management schematics and images
    - Add 6 hardware assembly and testing photos to hardware/
    - Add 4 electrical schematics and wiring diagrams to schemes/
    - Add 8 individual component photos to other/components/
    - Update section 4.2 in README.md with high-res schematic links
2026-09-12 feat(vision/comms): improve corner profile detection and simplify UART angle payload
2026-09-17 refactor(control): simplify wall follower target yaw calculation
2026-09-17 refactor(control): fix direction conventions for turns and yaw calculations
2026-09-17 fix: target yaw logi
2026-09-17 fix: target yaw logic
2026-09-18 fix: camera index to 0
2026-09-18 fix: camera index updated
2026-09-18 fix: update open challenge logic
    [ESP32bridge.py]
2026-09-19 fix: camera index assigned correctly
